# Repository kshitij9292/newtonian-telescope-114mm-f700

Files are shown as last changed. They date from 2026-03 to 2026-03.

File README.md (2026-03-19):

114mm Newtonian Telescope

Featured Component: 1.Non-Rotating Helical Focuser
https://www.printables.com/model/265768-non-rotating-helical-focuser-with-collet-for-hadle
    Design by: @ballanux

     Non-rotating helical focuser with collet for Hadley
      https://www.printables.com/model/265768-non-rotating-helical-focuser-with-collet-for-hadle
    Note: dont need to print (02_Focuser_Base.stl) I have modified & intergrated into 3d print

2. 8mm rod clamp
     @Nikki81
       https://www.printables.com/model/78990-8mm-rod-clamp  

Optical Specifications
Feature	Details
Aperture (D)	114mm
Focal Length (f)	700mm
Focal Ratio	f/6.14
Focuser Diameter	1.25" Standard

Bill of Materials (BOM)
1. Optics

    Primary Mirror: 114mm diameter, 700mm focal length.

    Secondary Mirror: ~25mm - 28mm minor axis elliptical mirror.

2. Structural Hardware

    Truss Tubes: Pultruded Square Carbon Fiber Tube (Hollow)

        Dimensions: 10mm (OD) × 8mm (ID) × 1000mm (L)

        Quantity: 3

    Linear Rails: 8mm Smooth Rod

        Dimensions: 8mm diameter × 500mm length

    Rail Support: SHF8 8mm Linear Guide Rod Support (Horizontal Bracket)

    Fasteners:

        M4 x 20mm Hex bolts

        M8 x 30mm Hex bolts

        M5 x 40mm Hex bolts

    Threaded Inserts: M4 and M8 brass inserts (Heat-set).

🖨️ Printing Guidelines

    Material: PETG, ASA, or ABS.

       CRITICAL: Avoid PLA. It will warp under direct sunlight or in a warm vehicle, which permanently ruins optical alignment (collimation).

    Infill: 40% (Gyroid or Cubic recommended for maximum rigidity).

    Wall Loops: 4 minimum (Ensures strength for the heat-set inserts and SHF8 mounting points).

🔧 Assembly & Collimation

    Insert Hardware: Heat-set the brass inserts into the printed parts. Ensure the SHF8 brackets are mounted to a perfectly flat surface 
    Primary Cell: Mount the 114mm mirror into the cell using the printed clips.

    Do not overtighten the clips; "pinching" the mirror causes astigmatism (distorted star shapes).

    Collimation: * Adjust the three M8 screws on the primary cell to center the reflection.

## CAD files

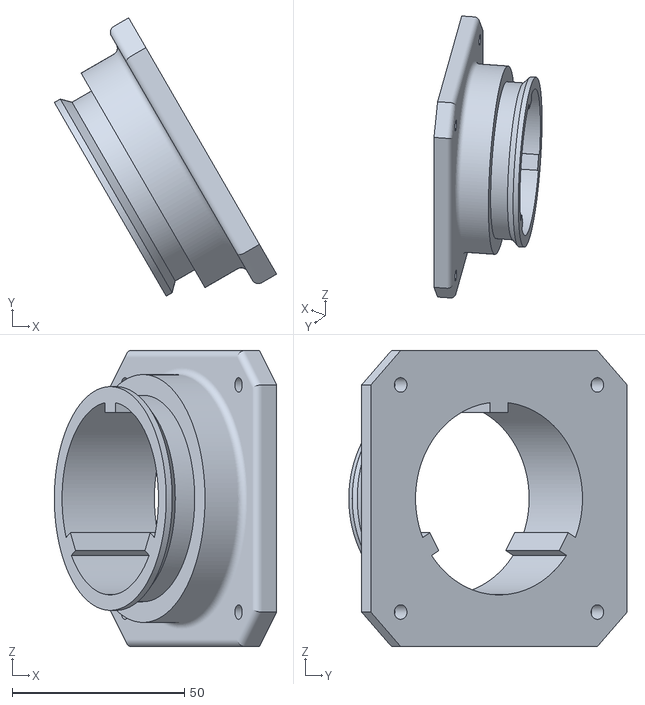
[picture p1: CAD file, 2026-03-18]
focuser_base.stl
64.6 x 80.9 x 86.0

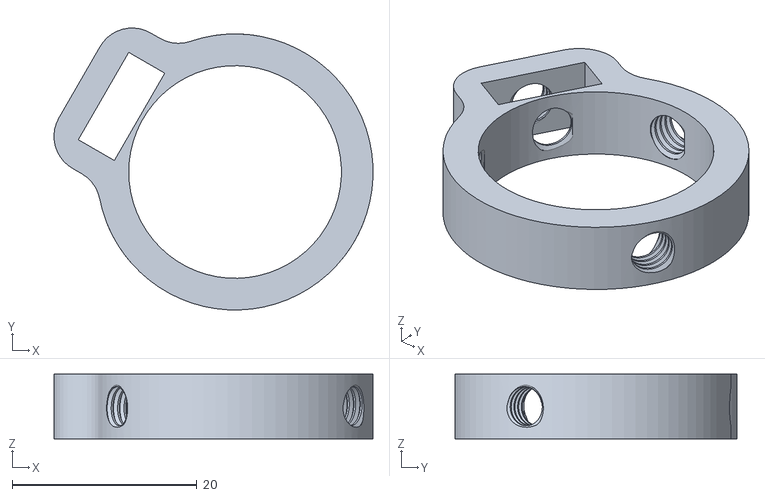
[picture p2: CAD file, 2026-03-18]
Ring1.stl
34.5 x 30.5 x 7.00

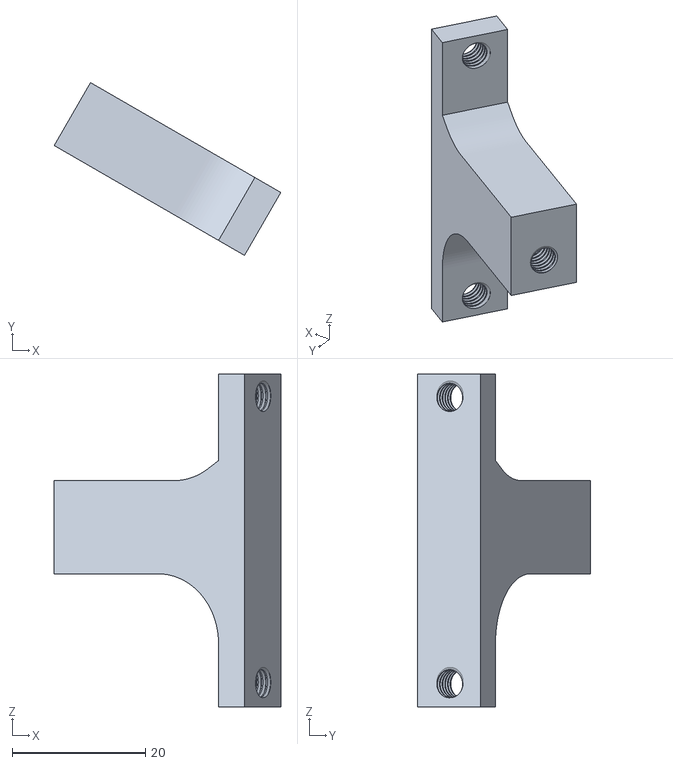
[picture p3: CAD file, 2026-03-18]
T.stl
34.0 x 25.9 x 50.0

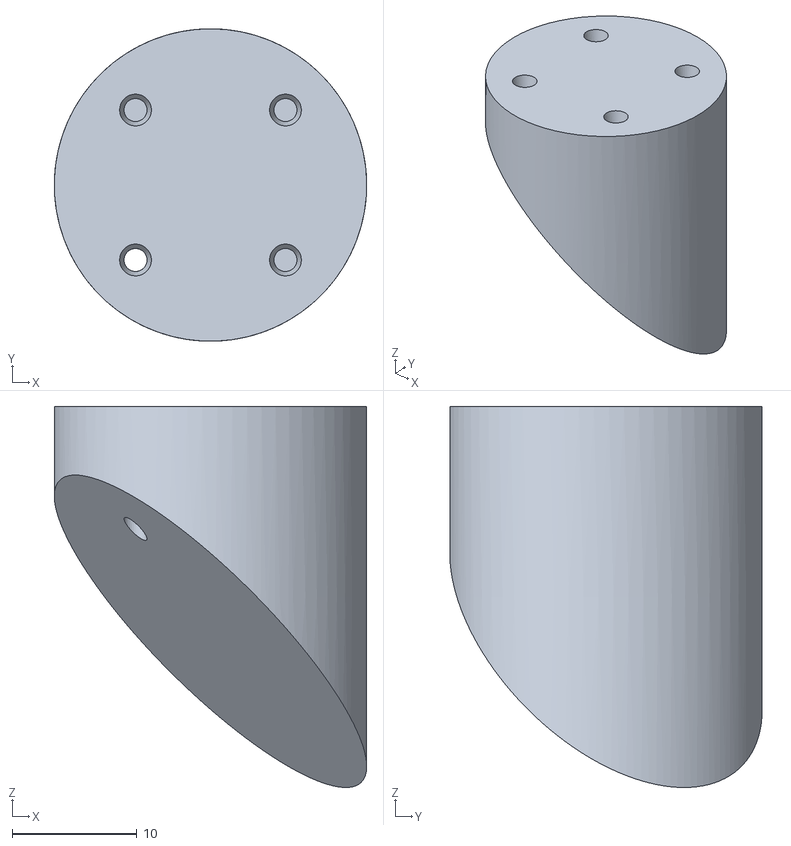
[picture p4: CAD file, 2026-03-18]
SEC.Support.stl
25.0 x 25.0 x 30.5

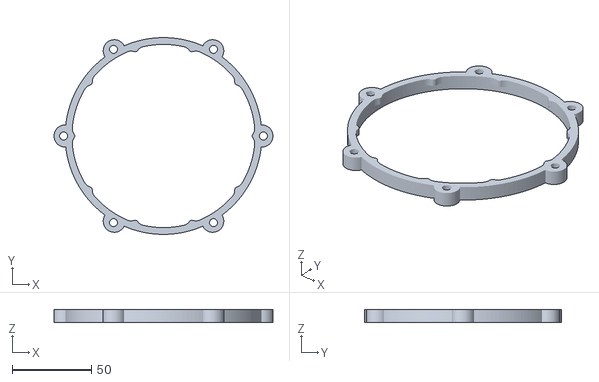
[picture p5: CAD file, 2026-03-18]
Body68.stl
138.0 x 124.0 x 8.00

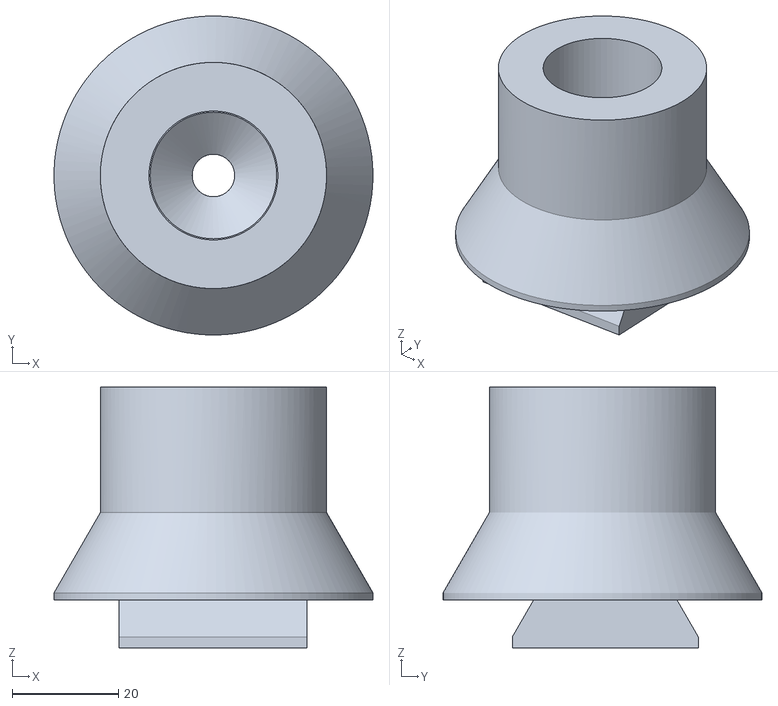
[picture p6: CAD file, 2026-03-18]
Body114.stl
60.0 x 60.0 x 49.0

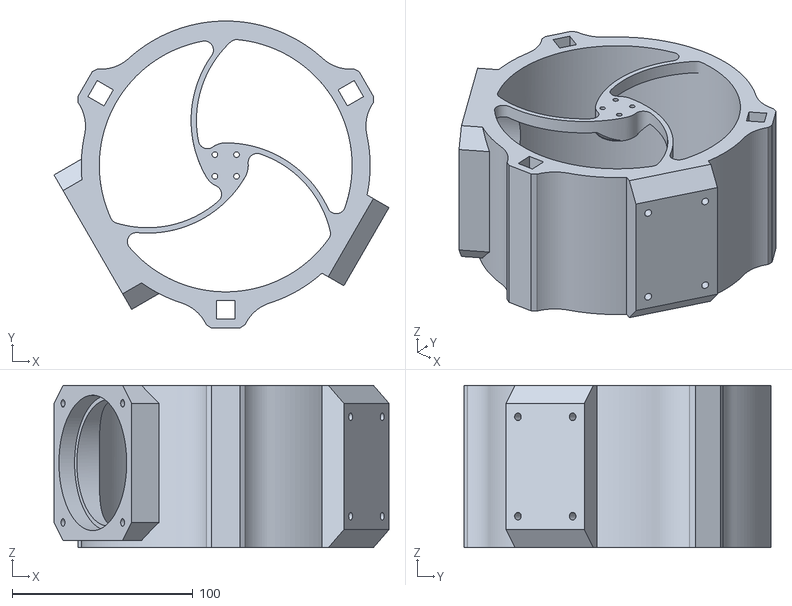
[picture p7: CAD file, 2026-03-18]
TOP.stl
185.6 x 170.0 x 90.0

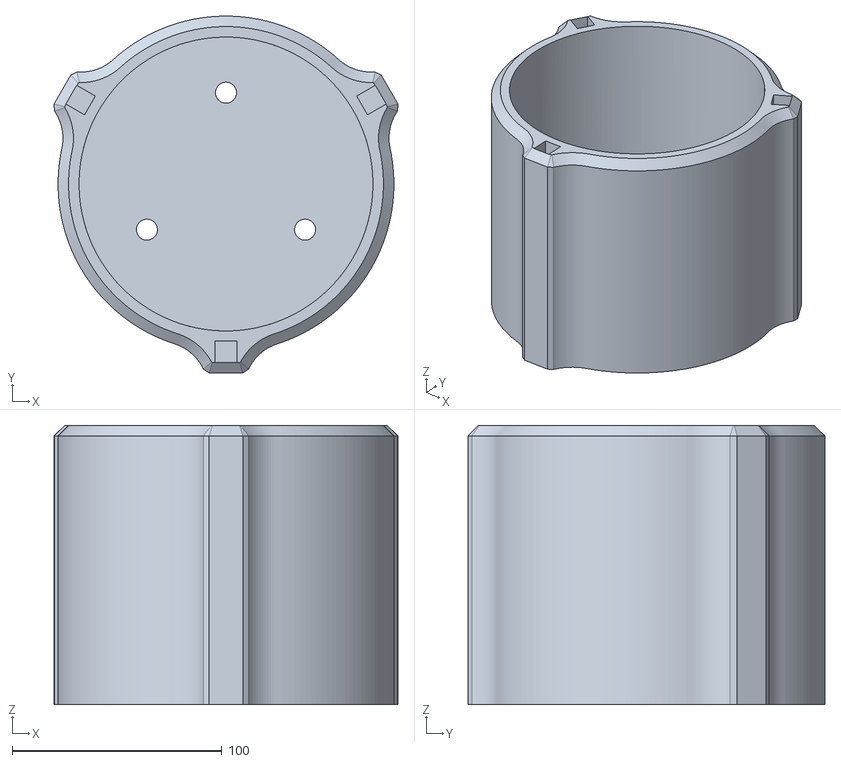
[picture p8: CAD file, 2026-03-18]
BOTTOM.stl
163.9 x 170.0 x 133.0

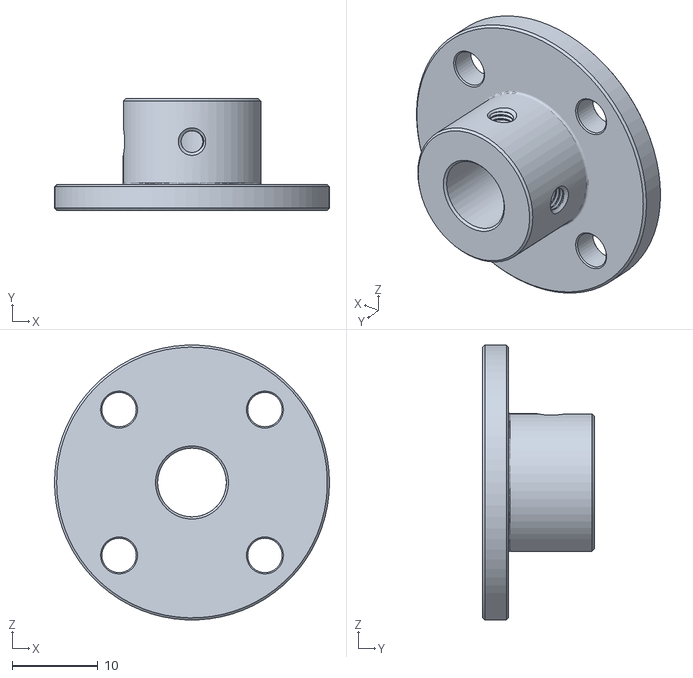
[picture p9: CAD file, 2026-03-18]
Body1.stl
32.0 x 13.0 x 32.0

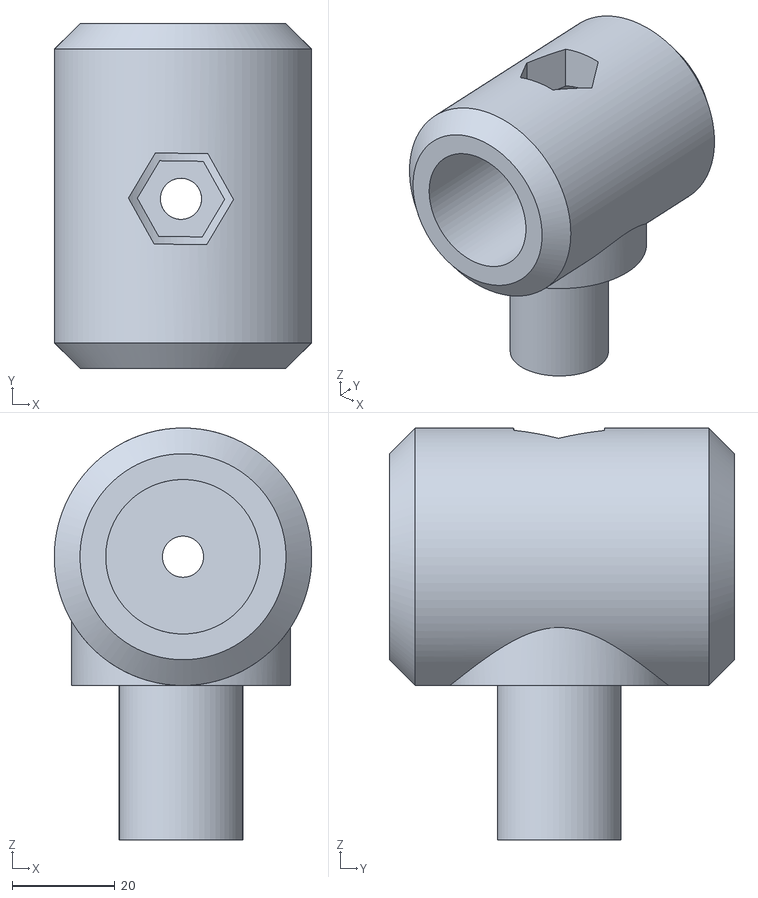
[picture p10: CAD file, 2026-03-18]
Body49.stl
50.0 x 67.0 x 80.0

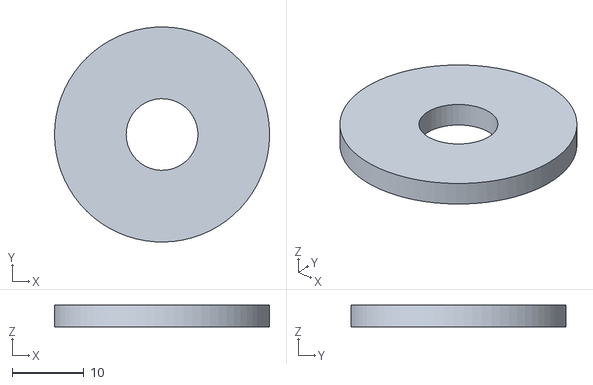
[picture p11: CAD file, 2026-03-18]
TPU.stl
30.0 x 30.0 x 3.00

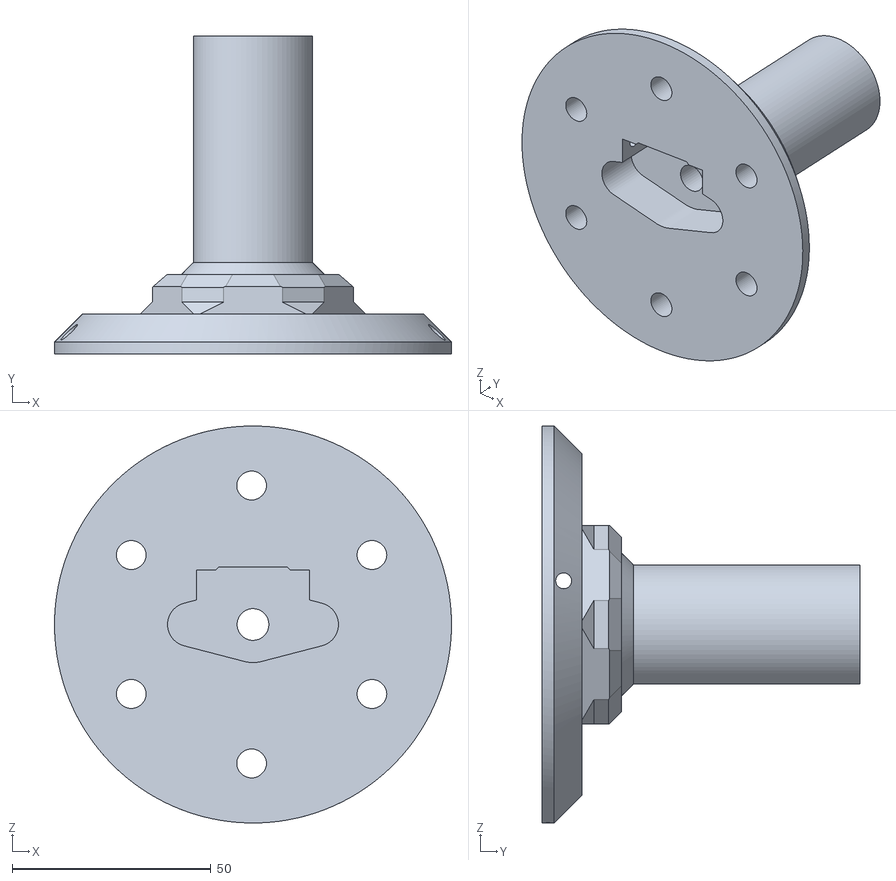
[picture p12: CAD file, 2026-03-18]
Body145.stl
100.0 x 80.0 x 100.0

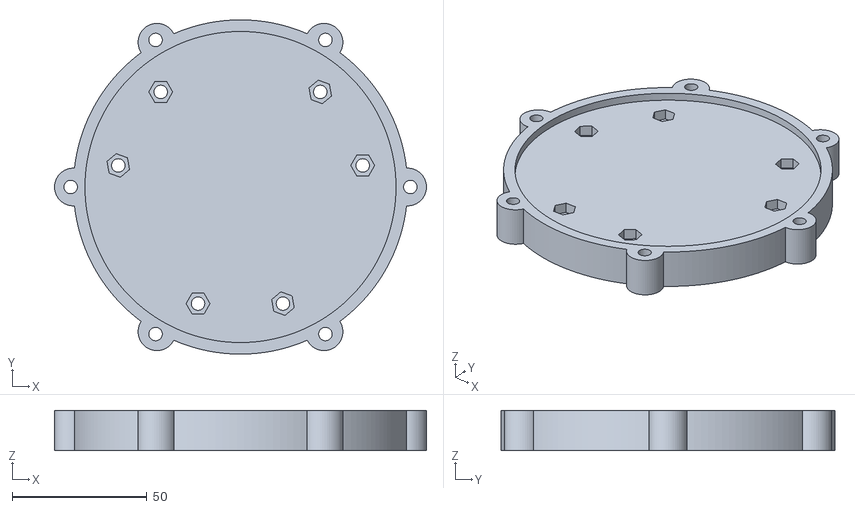
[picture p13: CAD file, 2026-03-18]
Body69.stl
138.0 x 124.0 x 15.0

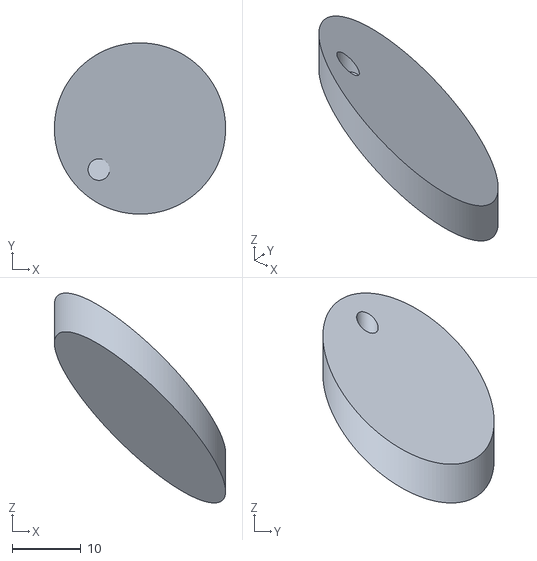
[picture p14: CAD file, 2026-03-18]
SECONDARY.stl
25.0 x 25.0 x 30.7

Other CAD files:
Ring2.stl
Body82.stl
BASE.stl
